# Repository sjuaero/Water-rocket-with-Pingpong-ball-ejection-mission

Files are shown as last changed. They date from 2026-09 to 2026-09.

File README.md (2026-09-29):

# Water Rocket with Ping-pong Ball Ejection Mission

A typical water rocket design designed to meet ping pong ball launch mission requirements.

1.5 L 페트병 하나를 동력원으로 **50 m 떨어진 목표 지점에 착탄**시키고, 비행 궤적상 **25 m 지점에서 탑재체(탁구공)를 사출**하는 물로켓을 설계·제작·발사한 팀 프로젝트입니다. CATIA로 구조와 사출 장치를 설계하고, MATLAB/Simulink와 OpenRocket으로 궤적·안정성을 예측한 뒤 실제 발사 결과와 비교해 오차 원인을 분석했습니다.

> 로켓공학및설계 (2026년 1학기) · 3인 팀 프로젝트

<p>
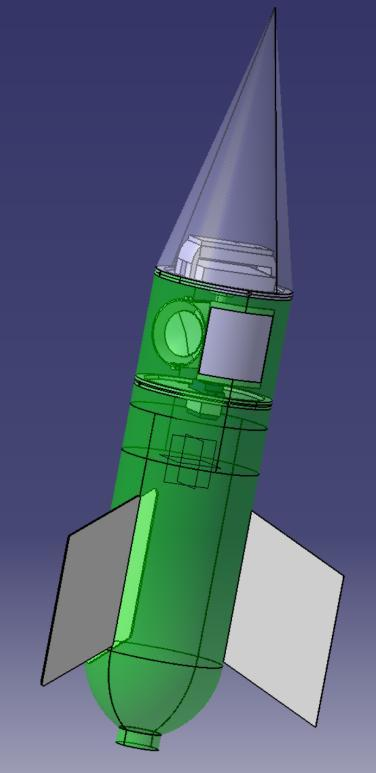
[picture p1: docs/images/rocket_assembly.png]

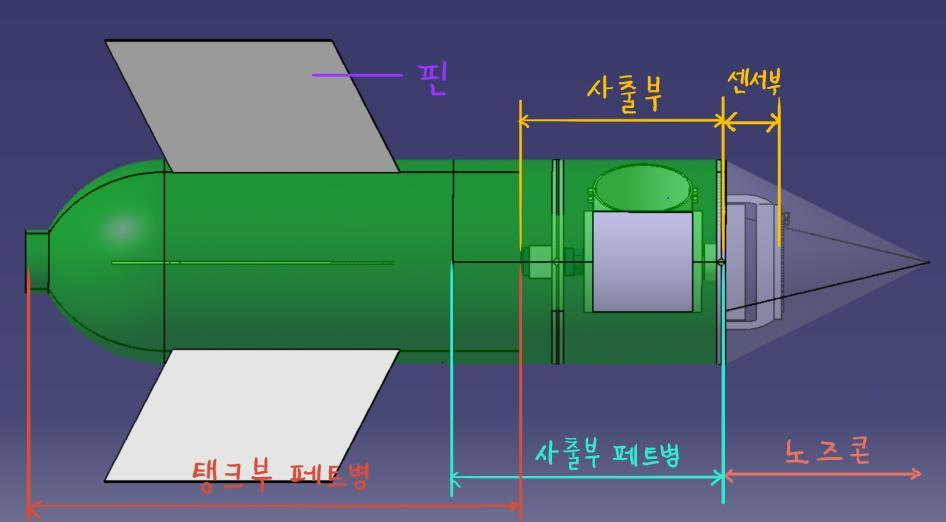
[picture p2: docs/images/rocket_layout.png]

</p>

---

## 미션 요구사항과 결과

| 항목 | 시뮬레이션 예측 | 실제 비행 | 차이 |
|---|---|---|---|
| 발사각 / 물 주입량 / 압력 | 50° / 0.58 L / 50 psi | 50° / 0.58 L / 50 psi | – |
| 최대 비행거리 (목표 50 m) | 49.04 m | **56.6 m** | +7.56 m |
| 총 체공시간 | 3.16 s | 3.8 s | +0.64 s |
| 탁구공 사출 시점 | 1.548 s | 2.05 s | +0.50 s |
| 탁구공 사출 위치 (목표 25 m) | 25 m | **약 23.7 m** | −1.3 m |

<p>
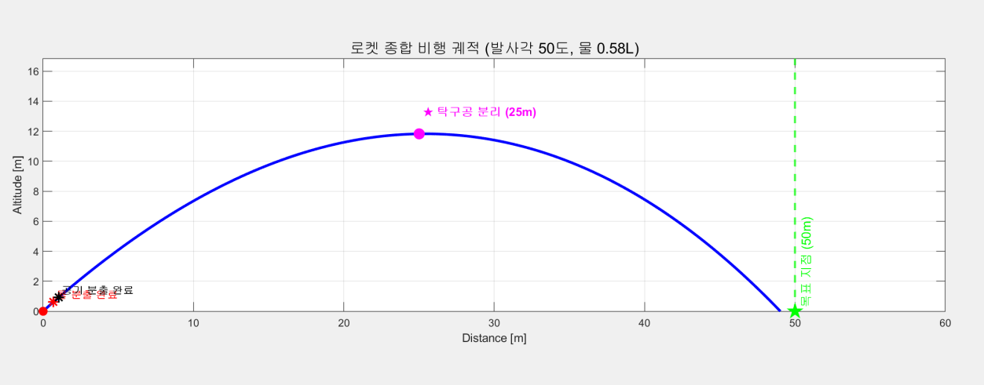
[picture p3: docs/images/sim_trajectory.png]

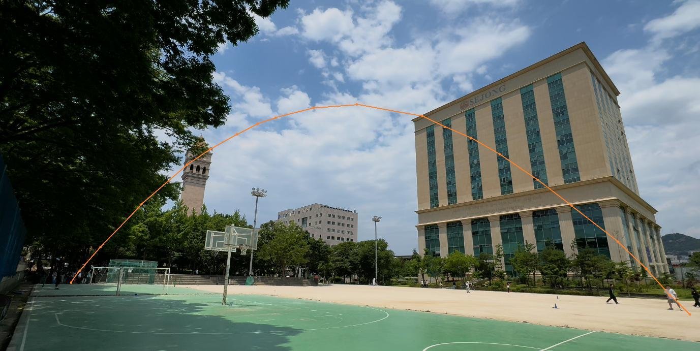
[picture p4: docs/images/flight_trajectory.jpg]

</p>

실제 비행 궤적과 사출 위치는 비행 중 BLE 통신 장애로 텔레메트리를 받지 못해 **촬영 영상을 프레임 단위로 분석해 복원**했습니다.

---

## 설계

### 1. 기체 구조와 비행 안정성

- **탱크부**: 칠성사이다 1.5 L 페트병을 가공하지 않고 사용했습니다. 50 psi에서 원주응력 38.81 MPa, 축응력 19.41 MPa로 PET 허용응력(약 89.7 / 66 MPa) 이내입니다. 반면 절단 후 접착하면 접합부 강도(테이프 0.154 MPa, 순간접착제 최대 4.2 MPa)가 부족해서 가공하지 않는 쪽을 택했습니다.
- **노즈콘**: 최대 속도 약 25 m/s(M ≈ 0.074)의 아음속이라 형상에 따른 항력 차이가 작습니다. 그래서 제작이 쉬운 원뿔형으로 하고, 직경 90 mm : 높이 180 mm(1 : 2)로 정했습니다. 소재는 경량 PP(클리어 파일)입니다.
- **무게중심 / 압력중심**: 부품별 실측 질량을 CATIA *Apply Material*에 밀도로 반영해 CG를 구했고(노즈콘 끝에서 **256.9 mm**), OpenRocket에서 CG를 override해 CP를 계산했습니다.
  - 물 0.58 L를 채운 직후에는 정적 마진이 −0.997 cal입니다. 다만 동압이 거의 0이고 물이 약 0.1 s 안에 모두 분사되기 때문에 영향이 작다고 판단했습니다.
  - 비행 중 안정 마진은 **0.243 ~ 0.276 cal**로, 전 구간에서 양수를 유지했습니다.

<p>
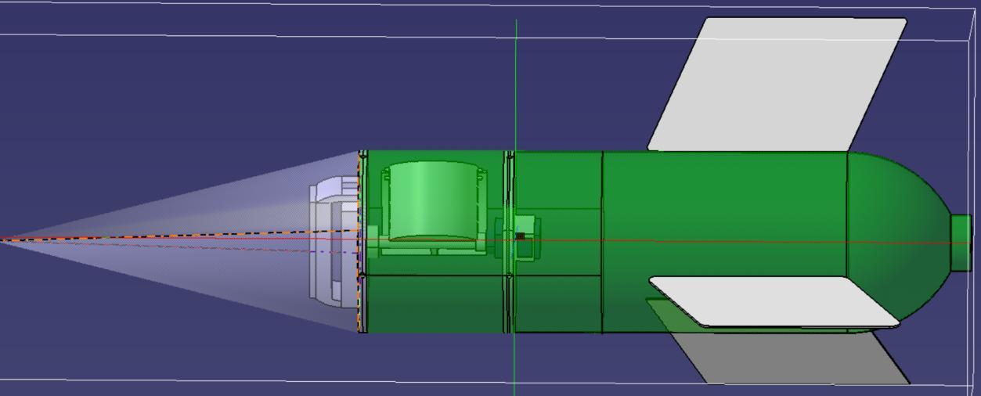
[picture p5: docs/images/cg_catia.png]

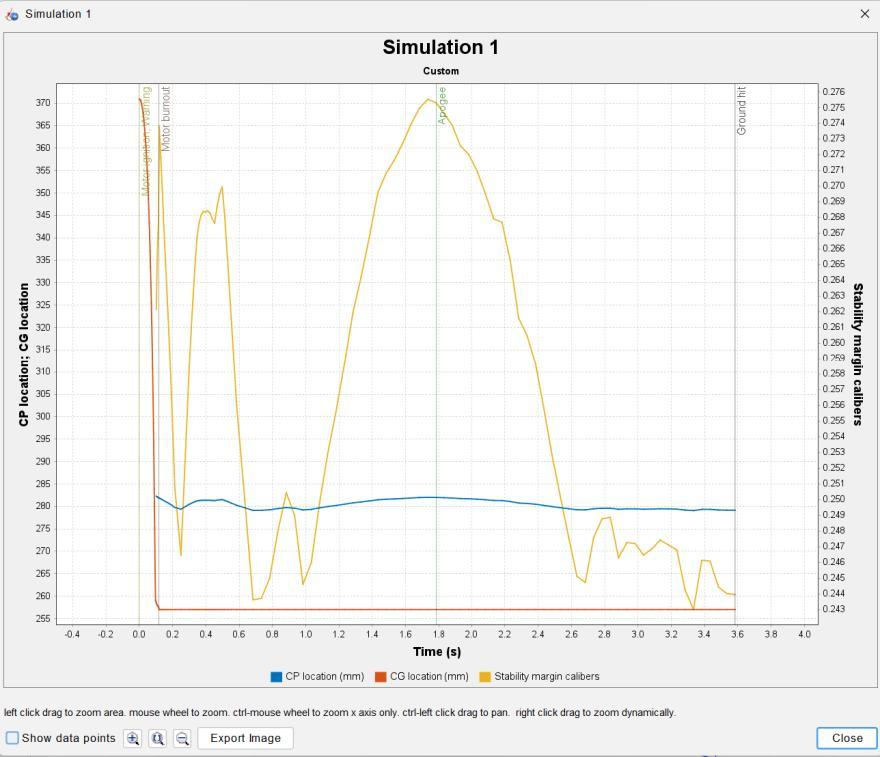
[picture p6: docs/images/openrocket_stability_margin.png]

</p>

### 2. 탁구공 사출 장치

두 가지 안을 설계했습니다.

| | 1안: 링크식 개폐문 + 스프링 | 2안(최종): 회전 실린더 + 슬링샷 |
|---|---|---|
| 방식 | 서보 → 평행 링크로 양쪽 문을 열고 스프링으로 밀어냄 | SG90 서보가 실린더를 회전시키면 고무줄에 걸린 Pusher Pad가 탁구공을 튕겨냄 |
| 결과 | 부품이 많고 작동 시간이 길어 **폐기** | 구조가 단순하고 가벼워 **채택** |
| CAD | [`cad/design_v1_link_door`](cad/design_v1_link_door) | [`cad/design_v2_final`](cad/design_v2_final) |

<p>
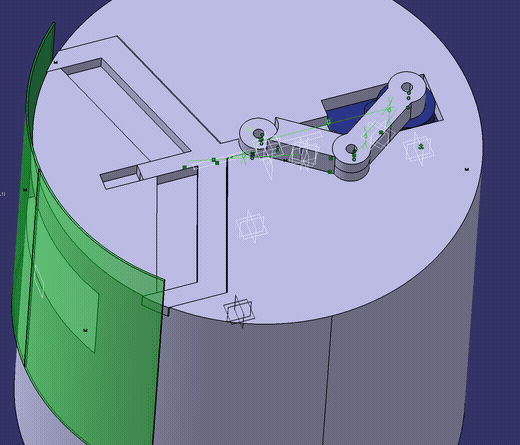
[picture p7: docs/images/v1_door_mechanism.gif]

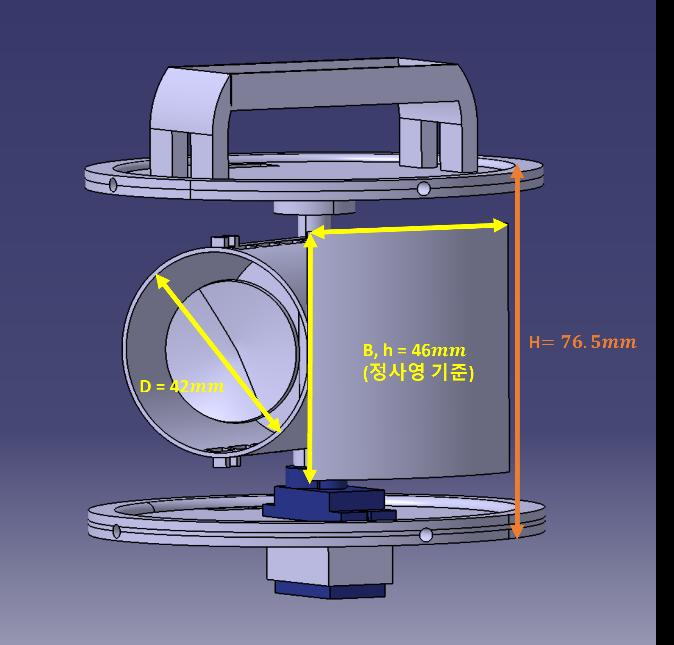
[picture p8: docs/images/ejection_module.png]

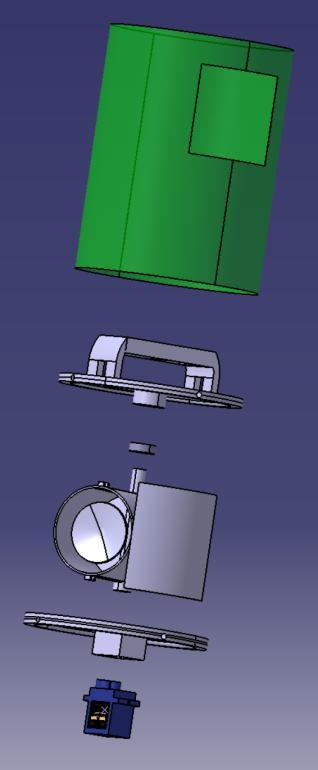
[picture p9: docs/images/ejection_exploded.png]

</p>

- 상판, 하판, 회전 실린더는 PLA+로 3D 프린팅했고, 상단 회전축에 베어링을 넣어 서보 출력에 따라 부드럽게 회전하도록 했습니다.
- 사출 지연 시간 예측값은 160.7 ms(고무줄 + 서보 + 전자장비 합산)입니다. 240 fps 슬로모션으로 측정한 값은 **167 ms**로, 예측과 7 ms 차이였습니다.

### 3. 비행 제어 및 데이터 수집 (Arduino Nano 33 BLE Sense)

IMU(가속도계·자이로)를 내장한 Arduino Nano 33 BLE Sense가 비행 컨트롤러 역할을 합니다. 로켓의 자세와 이동거리를 실시간으로 추정해 사출 서보를 구동하고, 비행 데이터는 BLE로 지상국(GCS)에 보냅니다. 상세 내용은 **[비행 소프트웨어 설계 문서](docs/flight_software.md)**에 정리했습니다.

```mermaid
stateDiagram-v2
    direction LR
    READY --> CALIBRATING: BLE 연결, 보정 명령
    CALIBRATING --> STANDBY: IMU 300샘플 평균
    STANDBY --> FLYING: 축방향 1.4 G 이상
    FLYING --> EJECTED: 27.7 m 또는 1.453 s
    EJECTED --> DUMPING: 1 G 1초 유지 (착지)
    DUMPING --> READY: 로그 전송 후 리셋
```

- **항법**: 자이로 적분으로 피치를 추정하고, 중력과 바이어스를 뺀 합성 가속도를 이중적분해 이동거리를 구합니다. 드리프트를 막기 위해 데드밴드 0.20을 적용했습니다.
- **사출 트리거**는 둘 중 먼저 만족하는 조건입니다.
  1. 추정 이동거리 **27.7 m** 도달 (직선 25 m에 해당하는 포물선 궤적 길이)
  2. 비행 시간 **1.453 s** 경과 (fail-safe)
- **데이터**:
  - 50 Hz로 최대 120 샘플을 RAM 버퍼에 저장합니다.
  - 착지 후 float을 int16으로 압축한 바이너리 패킷을 BLE로 보냅니다.
  - HTML 지상국 콘솔에서 로그를 받습니다.

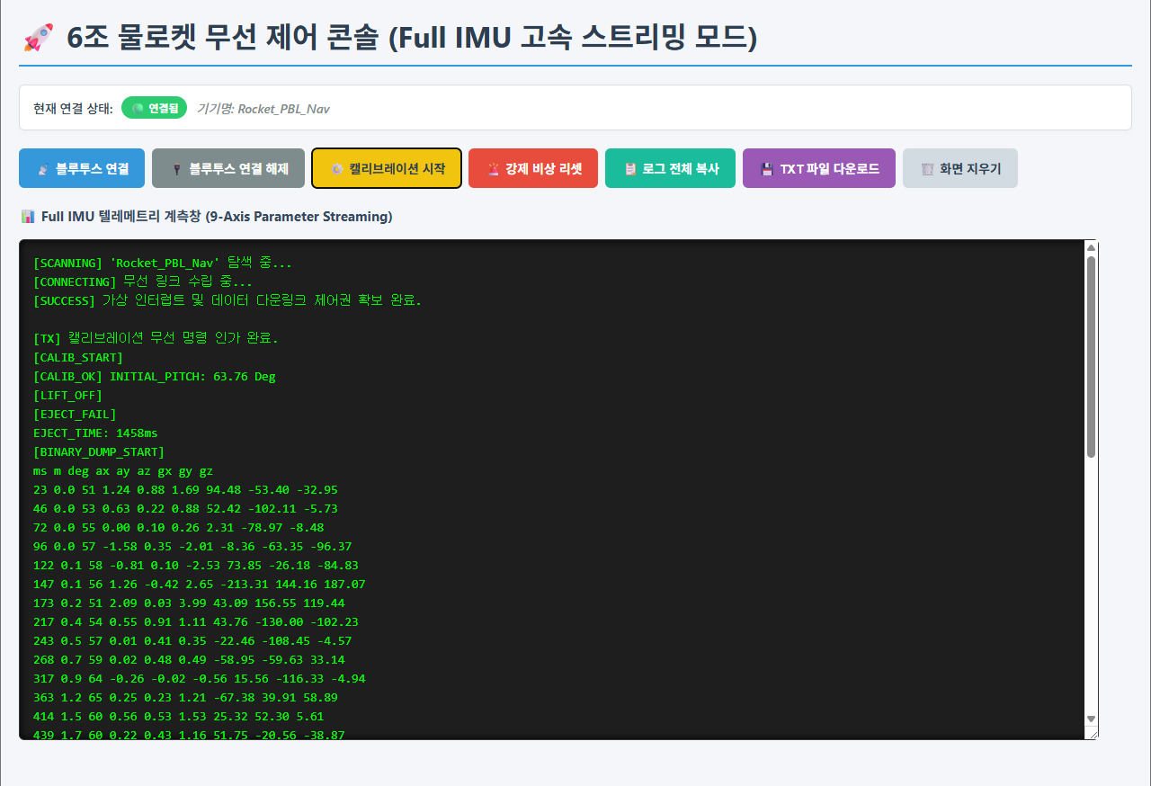
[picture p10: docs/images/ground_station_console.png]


---

## 오차 원인 분석

1. **배풍 효과**: 발사 당시 서풍 3 m/s가 불어 상대속도 기준 항력이 줄었고, 그만큼 비행거리가 늘었습니다.
2. **유량계수 과소평가**: 물/공기 유량계수를 1.0으로 두고 다시 계산하면 실제 비행거리와 0.5% 이내로 일치합니다. 다른 요인이 복합적으로 작용했다는 뜻으로 해석했습니다.
3. **사출 시스템 지연**: MCU 처리 시간과 서보 구동 지연이 시뮬레이션에 완전히 반영되지 않았습니다.
4. **발사 감지 지연**: 축방향 가속도 1.4 G를 넘어야 발사로 판정하기 때문에, 실제 발사 시각보다 늦게 타이머가 시작되었습니다. 그 결과 fail-safe 1.453 s 조건이 2.05 s에 작동했습니다.

---

## 시뮬레이션

<p>
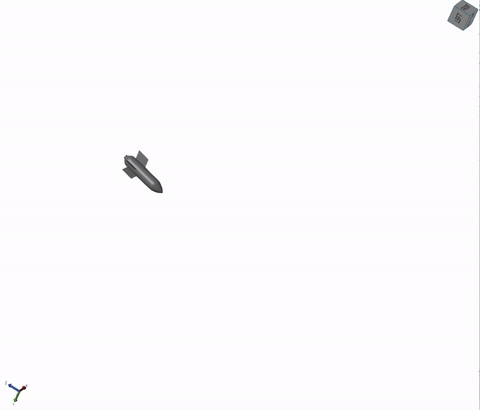
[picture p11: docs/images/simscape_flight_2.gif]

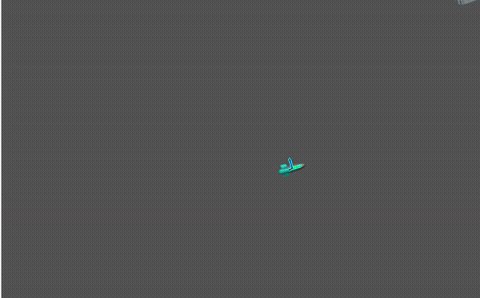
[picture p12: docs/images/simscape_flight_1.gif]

</p>
<p align="center"><sub>Simscape Multibody 6-DOF 비행 시뮬레이션 (<code>simulator_real.slx</code>, Mechanics Explorer)</sub></p>

| 파일 | 내용 |
|---|---|
| [`simulation/matlab/rocket3d_params.m`](simulation/matlab/rocket3d_params.m) | 추진·열역학·질량·CG·관성·공력 파라미터 (CATIA 측정값) |
| [`thrust_phase_func.m`](simulation/matlab/thrust_phase_func.m) | 물 분출 → 공기 분출 → 탄도비행 3단계 추력/질량유량 모델 (폴리트로픽 팽창) |
| [`aero_func.m`](simulation/matlab/aero_func.m) | Barrowman 선형화 3D 공력 모델 (항력 + 법선력 + 복원 모멘트) |
| [`mass_cg_inertia.m`](simulation/matlab/mass_cg_inertia.m) | 잔여 물 질량에 따른 질량·CG·관성텐서 보간 |
| [`stability_margin_timehistory.m`](simulation/matlab/stability_margin_timehistory.m) | 추력 구간 CG(t)–CP 안정 여유 시간이력 (단독 실행 스크립트) |
| [`water_simul.slx`](simulation/matlab/water_simul.slx) | Simulink 추력 모델 |
| [`simulator_real.slx`](simulation/matlab/simulator_real.slx) | Simscape Multibody 6-DOF 물로켓 모델 (**Simscape Multibody 필요**) |
| [`simulation/openrocket/water_rocket.ork`](simulation/openrocket/water_rocket.ork) | OpenRocket 모델. 물 0.58 L 추력곡선은 `motor/WaterRocket_0p58L.eng`로 불러오기 |

`mass_cg_inertia.m`은 `simulator_real.slx` 안의 MATLAB Function 블록 코드를 꺼낸 파일입니다. `stability_margin_timehistory.m`을 단독으로 실행할 때 필요합니다.

---

## 폴더 구조

```
Water-rocket-with-Pingpong-ball-ejection-mission/
├── cad/
│   ├── design_v2_final/        # 최종 기체 + 회전 실린더 사출 장치 (rotation_axis.CATProduct)
│   ├── design_v1_link_door/    # 1안: 링크식 개폐문 사출 장치 (link_dmu / ejection_assembly.CATProduct)
│   └── exports/                # 전체 기체 STEP·STL (zip)
├── simulation/
│   ├── matlab/                 # 추력·공력·질량 모델, Simulink / Simscape 모델
│   └── openrocket/             # .ork, 물로켓 추력곡선(.eng/.rse), CP-받음각 데이터
├── analysis/rubber_band_ansys/ # 슬링샷 고무밴드 ANSYS Workbench 해석
├── docs/
│   ├── flight_software.md      # 아두이노 비행 소프트웨어 설계 (FSM, 항법, 사출, 데이터 덤프)
│   ├── reports/                # 최종 보고서, PBL 개념설계(사출 메커니즘)
│   └── images/
└── coursework/nozzle_design/   # (같은 과목 개인과제) Bell vs Cone 노즐 설계, NASA CEA 분석
```

### CATIA 파일 열기

- CATIA V5에서 어셈블리(`.CATProduct`)를 열 때 파트 링크를 찾지 못하면 **File → Desk → Find**로 해당 폴더를 지정하면 다시 연결됩니다.
- `Arduino nano.CATPart`, `SG90 servomotor.CATPart`는 GrabCAD에 공개된 STEP 모델을 CATIA로 변환해 질량을 입힌 파일입니다.

## 보고서

- [로켓공학및설계 최종보고서](docs/reports/로켓공학및설계_최종보고서_6조.pdf)
- [비행 소프트웨어 설계 문서](docs/flight_software.md)
- [PBL 개념설계: 탁구공 사출 메커니즘](docs/reports/PBL_개념설계_탁구공_사출메커니즘.pdf)
- 개인과제: [노즐 설계 보고서 (Bell vs Cone)](coursework/nozzle_design/노즐_설계_보고서_Bell_vs_Cone.pdf) · [CEA 분석 보고서 (Equilibrium vs Frozen)](coursework/nozzle_design/CEA_분석_보고서_Equilibrium_vs_Frozen.pdf)

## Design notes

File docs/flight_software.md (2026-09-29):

# 비행 소프트웨어 설계 (Arduino Nano 33 BLE Sense)

물로켓의 비행 제어와 데이터 수집 소프트웨어 구조를 최종 보고서 내용만으로 정리한 문서입니다. 펌웨어 소스 코드는 포함하지 않습니다.

---

## 1. 하드웨어 구성

| 구성품 | 역할 |
|---|---|
| **Arduino Nano 33 BLE Sense** | 가속도계·자이로스코프가 통합된 IMU 기반 비행 컨트롤러(FC). 자세·이동거리 추정, 사출 판단, BLE 통신 |
| **SG90 서보모터** | 회전 실린더를 돌려 개폐문을 열고 탁구공을 슬링샷으로 사출 |
| **배터리 & 소켓** | 전원 (사출 장치 상단 공간에 장착) |
| **지상국(GCS)** | 웹 브라우저에서 동작하는 HTML BLE 콘솔 |

SD 카드 같은 내부 저장장치는 **발사체 질량을 줄이기 위해** 빼고, 모든 데이터를 BLE로 받도록 설계했습니다.

---

## 2. 유한 상태 기계 (FSM)

```mermaid
stateDiagram-v2
    direction LR
    READY --> CALIBRATING: BLE 연결, 보정 명령
    CALIBRATING --> STANDBY: IMU 300샘플 평균
    STANDBY --> FLYING: 축방향 1.4 G 이상
    FLYING --> EJECTED: 27.7 m 또는 1.453 s
    EJECTED --> DUMPING: 1 G 1초 유지 (착지)
    DUMPING --> READY: 로그 전송 후 리셋
```

| # | 상태 | 동작 |
|---|---|---|
| ① | `STATE_READY` | 하드웨어를 초기화하고 BLE 연결을 기다립니다. |
| ② | `STATE_CALIBRATING` | 정지 상태의 IMU 샘플 **300개**를 모아 초기 피치와 센서 바이어스를 계산합니다. |
| ③ | `STATE_STANDBY_DELAY` → `STATE_STANDBY` | 보정 직후 무선 통신 안정화를 위해 **500 ms 가드 타임**을 둔 뒤 발사 충격을 감시합니다. 축방향 가속도가 **1.4 G** 이상이면 발사로 판정합니다. |
| ④ | `STATE_FLYING` | 가속도·자이로로 이동거리를 실시간 계산하고 사출 조건을 감시합니다. |
| ⑤ | `STATE_EJECTED` | 서보를 구동해 탑재체를 사출하고, 착지할 때까지 충격 변화를 감시합니다. |
| ⑥ | `STATE_DUMPING` | RAM 버퍼에 쌓인 비행 데이터를 BLE 고속 패킷으로 전송하고 시스템을 리셋합니다. |

---

## 3. 비행 거리 추정 알고리즘

### ① 초기 자세와 센서 오차 (CALIBRATING)

지면에 정지한 상태에서 수집한 300개 샘플의 평균 $\overline{a}$를 씁니다.

```math
\theta_\text{init} = \operatorname{atan2}\!\left(\overline{a_{z,\text{raw}}},\ \overline{\sqrt{a_{x,\text{raw}}^2 + a_{y,\text{raw}}^2}}\right),
\qquad
\text{Bias}_z = \left(\overline{a_{z,\text{raw}}} - \sin\theta_\text{init}\right) g
```

### ② 비행 중 피치 추정 (FLYING)

정적 상태를 벗어나면 가속도로는 자세를 알 수 없습니다. 그래서 Y축 자이로를 시간에 대해 적분해 기울기를 갱신합니다.

```math
\theta_\text{current} = \theta_\text{prev} + \left(-\omega_y - \text{Bias}_{\omega_y}\right)\,dt
```

### ③ 3차원 동적 합성 가속도

원시값(g 단위)을 m/s²로 바꾸고, 추정 기울기에 해당하는 중력 성분과 바이어스를 빼서 **추력에 의한 가속도**만 남깁니다.

```math
a_x = a_{x,\text{raw}}\,g,\qquad
a_y = a_{y,\text{raw}}\,g,\qquad
a_z = \left(a_{z,\text{raw}} - \sin\theta_\text{current}\right) g - \text{Bias}_z
```

```math
a_\text{horizontal} = \sqrt{a_x^2 + a_y^2 + a_z^2}
```

### ④ 이중 적분으로 속도·거리 추정

```math
v(t) = v(t-dt) + a_\text{horizontal}\,dt,\qquad
s(t) = s(t-dt) + v(t)\,dt
```

- **노이즈 가드**: 가속도가 데드밴드(`ACCEL_DEADBAND = 0.20`)보다 작으면 정지로 보고 0으로 처리해 센서 드리프트를 1차로 억제합니다.
- 계산된 거리는 지구좌표계의 직선거리가 아니라 **궤적을 따라간 거리**입니다. 그래서 직선 25 m에 해당하는 포물선 궤적 길이인 **27.7 m**를 목표 거리로 정했습니다.

---

## 4. 사출 트리거

미션 실패를 막기 위해 두 조건 중 **먼저 만족하는 쪽**에서 서보에 신호를 보냅니다.

| 조건 | 값 | 목적 |
|---|---|---|
| 추정 이동거리 | **27.7 m** | 주 조건: 궤적상 25 m 지점 |
| 비행 시간 | **1.453 s** | fail-safe: 비행 시간이 짧고, 진동 같은 외란으로 거리 추정이 틀릴 경우에 대비 |

### 사출 지연 보정

| 구성 | 값 |
|---|---|
| 개념설계 예측: $t_\text{rubber} + t_\text{servo} + t_\text{elec}$ | 160.7 ms |
| 실측 (240 fps 슬로모션, 신호 → 탁구공 이탈) | **167 ms** (± $t_\text{elec}$ = 33.5 ms → 133.5 ~ 210.5 ms) |

- 예측과 실측 차이는 7 ms였습니다.
- 25 m 상공에서 33.5 ms가 만드는 거리 오차는 수 cm 수준이라 무시했습니다.
- 펌웨어에는 **167 ms 지연을 미리 빼서** 반영했습니다.

---

## 5. 데이터 저장과 덤프

| 항목 | 내용 |
|---|---|
| 로깅 주기 | 20 ms (**50 Hz**) |
| 버퍼 | RAM 배열, 최대 **120 샘플** (`MAX_LOG_SAMPLES`) |
| 착지 판정 | 사출 후 3축 가속도 크기 $\sqrt{a_x^2+a_y^2+a_z^2}$가 **1.0 G 부근에서 1000 ms** 유지 |
| 전송 방식 | 문자열 대신 구조체를 1바이트 배열로 직렬화한 **바이너리 패킷** (`bleWriteBinary`) |
| 압축 | float 값에 10 또는 100을 곱해 **int16**으로 전송 |
| 로그 형식 | `ms, m, deg, ax, ay, az, gx, gy, gz` (시간, 거리, 피치, 3축 가속도, 3축 각속도) |

### 지상국 (HTML BLE 콘솔)



- 상단 버튼: 블루투스 연결/해제, 캘리브레이션 시작, 강제 비상 리셋, 로그 전체 복사, TXT 파일 다운로드, 화면 지우기
- 하단 창: 로켓의 현재 상태(`CALIB_START`, `CALIB_OK`, `LIFT_OFF`, `EJECT_*`, `BINARY_DUMP_START`)와 비행 로그를 표시

---

## 6. 실제 운용 결과와 한계

| 항목 | 결과 |
|---|---|
| 지상 시험 | 사출 장치와 초기 시스템 구동은 정상이었고, 사양상 통신거리도 목표치(50~100 m)를 만족했습니다. |
| 실제 발사 | BLE 통신 장애로 유효 통신거리가 크게 줄어 비행 중 데이터를 안정적으로 받지 못했습니다. 대신 **촬영 영상을 프레임 단위로 분석**해 궤적과 사출 시점을 복원했습니다. |
| 사출 시점 | 설계 fail-safe는 1.453 s인데, 실제로는 **2.05 s(약 23.7 m 지점)**에 사출됐습니다. |

**원인 분석**
- fail-safe 조건만 있었다면 사출이 1.453 s를 넘을 수 없습니다.
- 그런데 2.05 s에 사출됐다는 건 **발사 시각을 늦게 인식**했다는 뜻입니다.
- 축방향 가속도가 1.4 G를 넘어야 발사로 판정하는 구조라서, 발사 → 감지 → 시간 측정 사이에 지연이 생긴 것으로 분석했습니다.
- MCU 처리 시간과 서보·개폐문의 기계적 지연도 시뮬레이션에 완전히 반영되지 않았습니다.

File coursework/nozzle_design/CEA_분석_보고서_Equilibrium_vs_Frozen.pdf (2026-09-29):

로켓공학및설계 CEA 분석 보고서

## CEA 분석 보고서

# NASA CEA를 이용한 로켓 노즐의

# Equilibrium 및 Frozen 조건 비교 분석

세종대학교 기계항공우주공학부

항공우주공학과

2026년 4월 17일

## 1. 환경 정의

- 1.1 공통 조건

: 먼저 로켓의 성능을 분석하기 위해 공통적으로 적용되는 가정이 있다.

1. 준 1 차원(Quasi-One Dimension) 상의 정상(Steady), 연속체 유동으로 가정한다.
2. 연소실(Chamber) 내 Total cond.로 가정하고 그 내부 속도를 없다고 가정한다.
3. 등엔트로피 과정인 가역단열 팽창이 발생함을 가정한다.
4. 이상 기체로 가정한다.
5. 연소실(Chamber) 내에서는 화합물 반응 간 화학적 평형이 유지된다.

위와 같은 가정들을 통해서 먼저 추진제 내 화합물 반응으로 발생되는 에너지 중 각 반응물마다 생성엔탈피의 차이를 단열가역 가정 내에서 최대한 에너지를 발생시키는 환경을 조성할 수 있다.

아래는 교안(강의자료#11)에서 제공한 해석 조건을 몇 가지를 제외하고 공통적으로 적용하게 된다.

파라미터 | 값 | 비고
연료 | H₂(L) | 액체 수소, 20.27K
산화제 | O₂(L) | 액체 산소, 90.17K
연소실 압력 (P) | 53.317 bar (773.3 psia)
O/F 혼합비 | 5.551 | 연료 농후 조건
압력비 (Pc/Pe) | 10, 100 | 두 가지 출구 조건
초음속 면적비 (Ae/At) | 25, 50 | 두 가지 노즐 출구
연소실 수축비 (Ac/At) | 1.58 | FAC 모드에서만 적용
계산 조건 | Shifting Equilibrium + Frozen | 두 조건 동시 계산

*FAC : Finite Area Combustor

- 1.2 해석 방식

### 1.2.1 Shifting Equilibrium (화학평형 해석)

노즐 팽창 과정에서 연속적으로 변화하는 압력과 온도 조건에 따라 모든 분자 화학종 사이의 화학 평 형이 순간적으로 유지된다고 가정하는 모델이다. 즉, 가스의 조성이 노즐을 따라 계속 변화(shift)하며, 연소실에서 존재하던 H, OH, O 등의 단원자 및 이원자가 재결합 반응을 통해 엔탈피를 추가로 방출함 으로써 더 많은 운동 에너지로 전환된다.

### 1.2.2 Frozen Composition (동결 조성 해석)

목(throat) 이후 노즐 팽창 과정에서 화학 조성이 고정(동결)된다고 가정하는 모델이다. 연소실에서 형 성된 조성이 그대로 유지되어 추가적인 화학 반응이 없으므로, 단원자 및 이원자의 재결합 에너지를 활용하지 못한다. 따라서 Shifting 조건 대비 성능이 1~4% 낮게 예측되는 보수적인 접근법이다.

### 1.2.3 Finite Area Combustor (FAC) 모드

마지막으로 진행되는 해석에서는 실제 연소실의 유한한 크기를 반영하기 위해 FAC 모드를 적용하였 다. 연소실-목 수축비(Ac/At = 1.58)를 입력하여 Injector face와 Combustor end 위치에서의 열역학 적 상태를 별도로 계산함으로써 교재 TABLE 5-4와 거의 동일한 구조로 진행하였다.

## 2. 해석 Input 설정

- 2.1 교안 35p, 36p 에 대한 Equilibrium/Frozen Input 설정

: Input 설정 과정을 사진으로 다 나타내는 것에 분량이 많아질 것을 우려하여 위에서 언급한 공통

조건을 교안에서 설명해두었던 방식 그대로 따라 적용하고 Final 탭에서 설정된 것을 확인하면 다음과 같다.

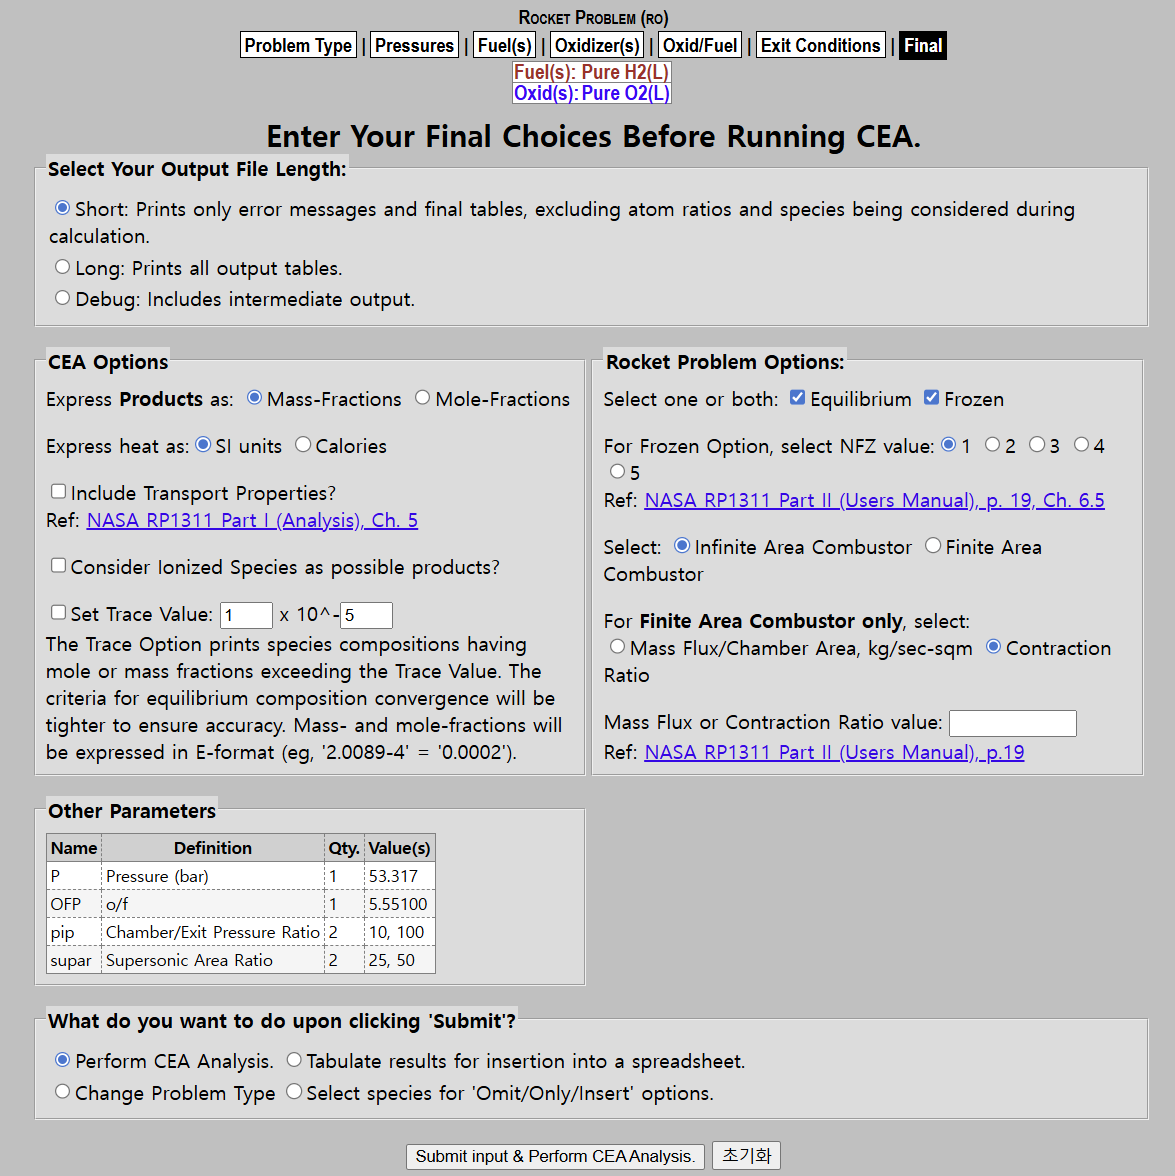
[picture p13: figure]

그림 1. 주어진 조건 하에서의 NASA CEA Equilibrium/Frozen 분석 Final Tap

먼저 위의 Short 설정을 통해 최종 결과 테이블만 출력하도록 하고, 아래 CEA Options 에서 연소 생성물 조성을 질량 분율로 표현하여 교안결과와 비교할 것이므로 Mass-Fractions 로 설정과 함께 SI Unit 으로 설정한다. 그 옆에서는 Equilibrium/Frozen 설정을 모두 키고 Frozen 의 경우는 Chamber 내에서만 가정하므로 ‘1’로 선택했다. 일단 Infinite area Combustor 로 설정해 앞서 가정해둔 Total Cond.를 유지하도록 한다. 그리고 아래 Other Parameters 에서 보이듯이 공통 조건이 잘 적용되어 있음을 확인할 수 있다.

- 2.2 교안 37p 예시에 대한 Input 설정

앞의 공통조건은 다 동일하게 적용하되, 바꾸어야 하는 조건은 Final Tap 에서 적용해야 한다. 적용된 변경점은 아래 사진을 통해 확인할 수 있다.

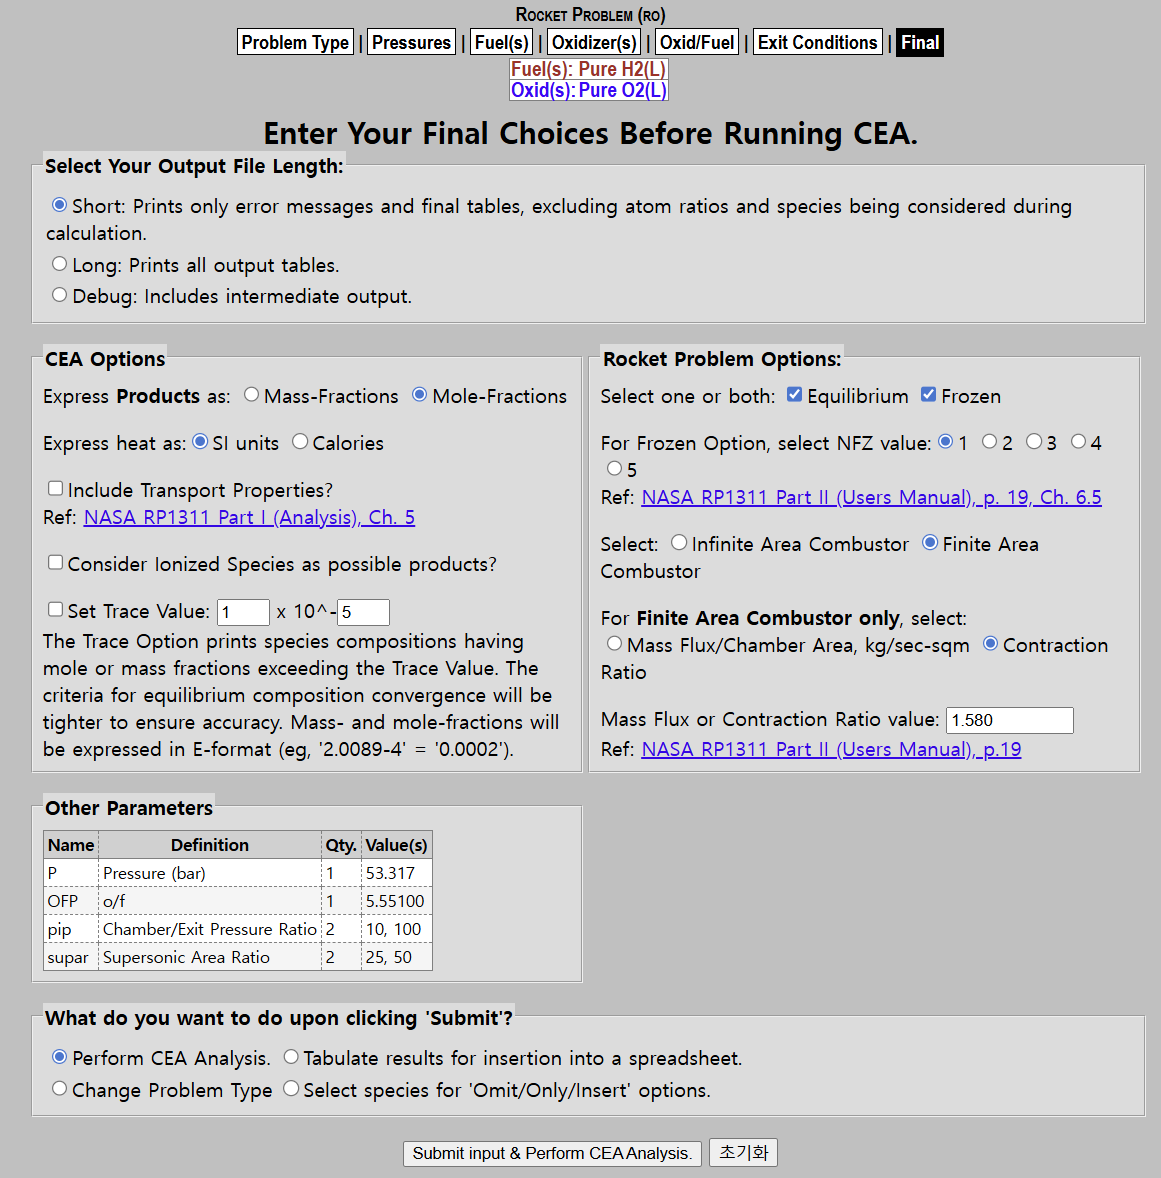
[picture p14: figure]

그림 2. 주어진 조건 하에서의 NASA CEA Finite Area Combustor 분석 Final Tap

이 경우에서는 일단 CEA Options 내 표현 방식을 Mole-Fractions 로 바꾸었다. 강의교안 #11 의 37p 에서의 예시에서 동일한 방식으로 표현되어 있어 이렇게 설정해두었다. 그리고 아래 Rocket Problem Options 에서 Finite Area Combustor 로 설정하였는데, 이렇게 되면 앞서 가정된 실제 유한한 크기의 연소실로 고려되므로 비-등엔트로피과정이 된다. 즉, 화학적 조성이 계속 변화하게 되므로 Equilibrium/Frozen 조건은 활성화되지 않는다. 이렇게 설정한 이유도 교안 37p 에서 주어진

연소실 수축비 조건에 의해 Injector 와 Combustion 에 대한 물성치가 활성화 된 것을 확인하고 이를 활성화하게 된 것이다. 그 아래에 수축비 1.580 을 대입한 것을 확인할 수 있다. 그리고 그 아래 Chamber 내 압력 및 추진제 화합물 비율 등의 공통 조건은 동일하게 적용되어 있다.

## 3. 해석 결과

먼저, CEA 프로그램 해석 결과에서 먼저 등장하는 것은 조건이 알맞게 적용되었는지 확인할 수 있다.

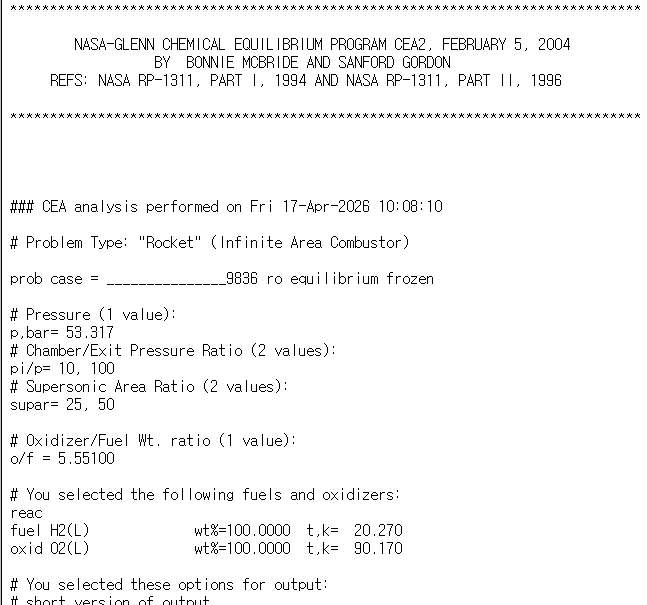
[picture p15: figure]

그림 3. 적용된 동일 물성치의 조건 확인

- 3.1 Infinite Shifting Equilibrium/Frozen Case and Finite Case 해석 결과

### 3 가지의 경우에 대한 CEA 결과는 동일 조건 하에서 몇가지만 조정된 채로 구한 각 챔버 및 목, 그리고

출구 단면적에서의 물성치 결과는 아래의 그림 4, 5, 6 과 같다. 교안과 비교했을 때 온도나 특성배기속도, 비추력 등에서는 소수점단위의 조금의 오차만 존재하여 오차율이 매우 작은 소수정도로 나타났다. 따라서, 결과적으로 유의미한 결과를 얻었다고 판단할 수 있다.

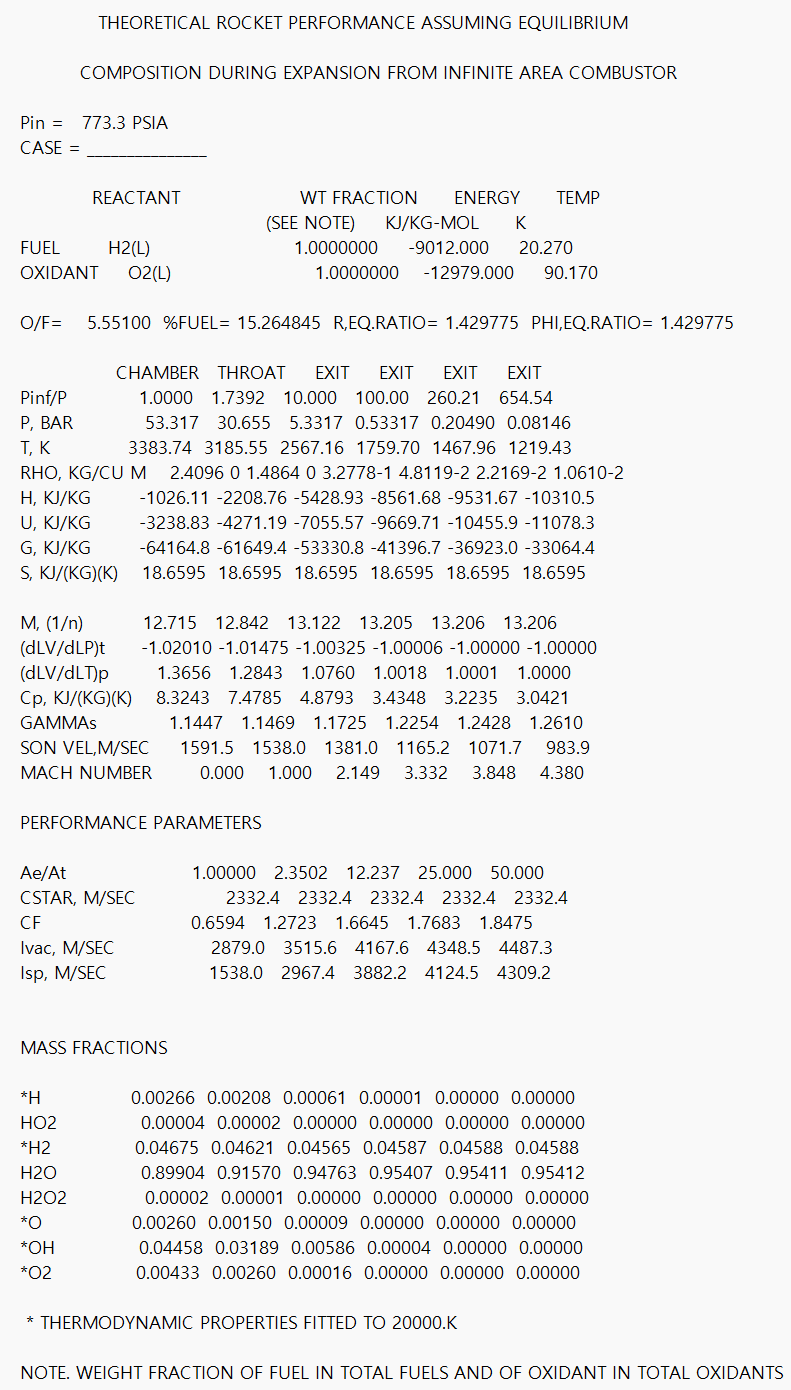
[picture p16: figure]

그림 4. Infinite Shifting Equilibrium 조건 상에서의 해석 결과

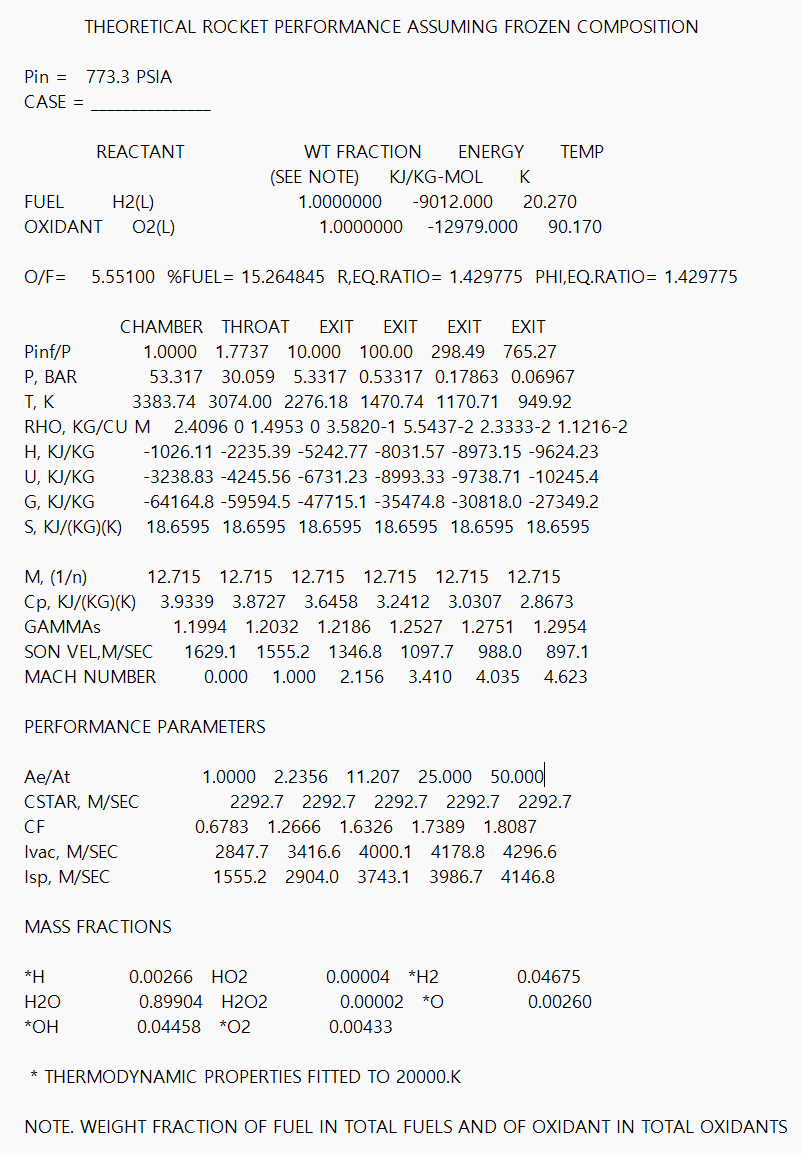
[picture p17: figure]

그림 5. Infinite Frozen 조건 상에서의 해석 결과

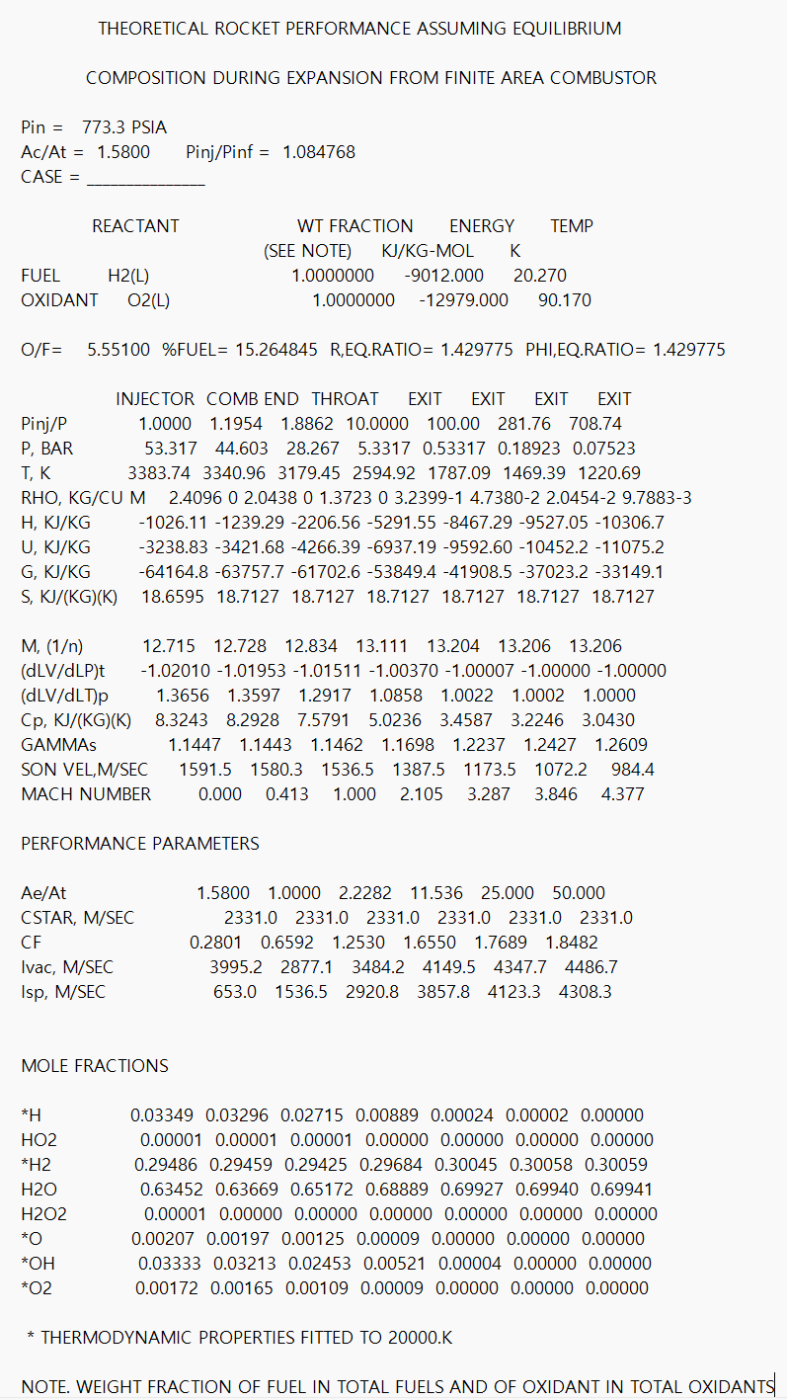
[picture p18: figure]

그림 6. Finite 조건 상에서의 해석 결과

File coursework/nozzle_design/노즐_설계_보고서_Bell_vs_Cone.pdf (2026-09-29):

로켓공학및설계 노즐 설계 보고서

## 노즐 설계 보고서

# 동일 조건 상 Bell 과 cone 형상 노즐 간 차이

세종대학교 기계항공우주공학부

항공우주공학과

2026년 3월 26일

## 1. 노즐 파라미터 계산

- 1.1 공통 조건

: 먼저 각 형상별 함수를 구하는 과정은 Matlab 상에서 m 단위를 기준으로 계산하였다.

주어진 조건 r* = 0.1m, r_e = 1m, L = 2m 의 길이 제한과 더불어, 노즐목 부근에서의 형상 반경은 xy 좌표계 기준 (0,0.2)에서의 r* 반경을 가지는 원호를 radian 기준 [6/4pi, 7/4pi] 사이에서만 나타내어야 한다.

- 1.2 이차함수형 Bell 형 곡선 구하기

: 위 공통 조건과 함께, 다음의 조건을 적용시켜야 한다.

조건 1. 원호의 끝점과 이차함수의 시작점이 일치해야 함.

조건 2. L = 2m 인 노즐 끝의 y 좌표는 r_e = 1m 로 맞추어야 함.

조건 3. 원점으로부터 L = 2m 만큼 떨어진 위치에서의 이차함수 곡선은 기울기가 0.

다음과 같은 조건들을 통해 세 개의 방정식을 있고, 아래와 같이 행렬계산으로 바꾸어 이차함수

y = Ax

2 + Bx + C

의 미정계수를 구할 수 있게 된다.

먼저, 원호와 곡선 간 만나는 지점을 x_c, y_c 라 하면, 주어진 각도 theta = pi/4 에 따라

x_c = r ∗ cos(theta)

y_c = 0. 2 − r ∗ sin(theta)

그럼 3 개의 조건식에 대한 방정식을 나열하면,

조건 1 : A ∗ x_c

2 + B ∗ x_c+ C = y_c

조건 2 : A ∗ L

2 + B ∗ L + C = r_e

조건 3 : 2A ∗ L + B = 0

[

x_c

2 x_c 1
L
2 | L | 1
2L | 1 | 0

][

A
B
C

] = [

y_c
r_e
0

]

위 행렬식을 matlab 에서 역행렬을 구하는 \(역슬래쉬) 계산을 통해 미정계수를 구하였다.

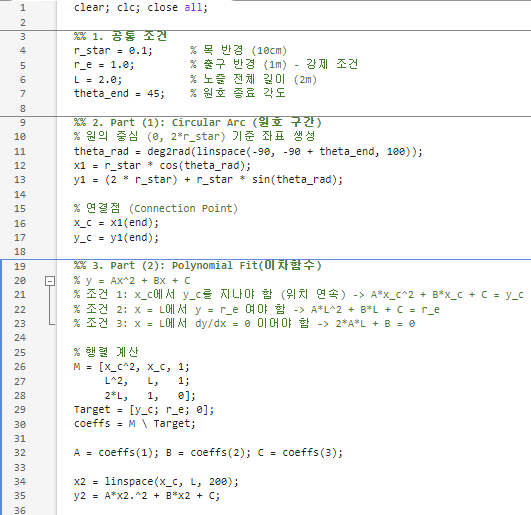
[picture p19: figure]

그림 1. 이차함수형 Bell 미정계수 구하는 코드

### - 1.3 일차함수형 Cone 형 직선 구하기

앞서 공통 조건에서 L 은 미지수가 되어 조건이 줄어들지만 일차함수를 구하기에 경계 조건과 미지수는 동일하게 만족된다. 먼저 a = 15 도의 cone angle 이 주어졌으므로 이 일차함수의 기울기는 tan(15°) 가 된다. 그리고 앞서 조건 1. 원호의 끝점과 이차함수의 시작점이 일치해야 함. 을 이용하여 일차함수의 형태를 구할 수 있게 된다.

y = tan(15°)x + a

접촉점(xc
, yc

) ⇒ yc = tan(15°) ∗ xc + a , a = y_c − tan(15°) ∗ xc

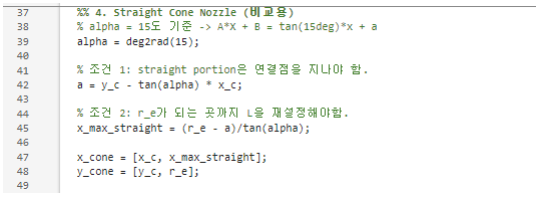
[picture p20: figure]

그림 2. 일차함수형 Nose 미정계수 구하는 코드

- 1.4 미정계수 결과 및 plot, 결과 비교

다음 시각화 과정을 통해 각 노즐형상 별 미정계수 및 cone 의 총 형상 길이를 구한 결과 아래와 같다.

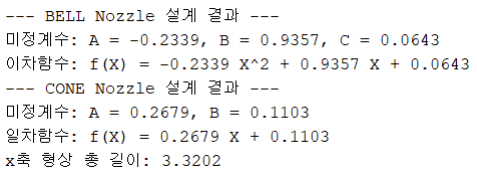
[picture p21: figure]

그림 3. 미정계수 결과 및 길이 비교

공통 조건을 만족시킬 때, 이차함수 bell 형태일 때의 L = 2m 보다 약 1.3202m 더 길게 cone 의 총 형상 길이를 3.3202m 로 형상설계해야 함을 알 수 있다.

이상추력 대비 실제 추력에 대한 비율을 의미하는 the correction factor λ (https://namu.wiki/w/%CE%9B) 를 고려해보았을 때,

동일한 면적비 기준에서 Bell 형상의 경우 노즐 출구에서의 곡선이 수평하게 끝나도록 만들었기에

λ
bell (https://namu.wiki/w/%CE%9B)

=

1
2

(1 + cos 0) = 1

여기에 원추형 노즐의 경우에서는 일정 각도 15 도로 설계하였으므로, 출구에서의 factor 는

λ
cone (https://namu.wiki/w/%CE%9B)

=

1
2

(1 + cos 15°) = 0.983

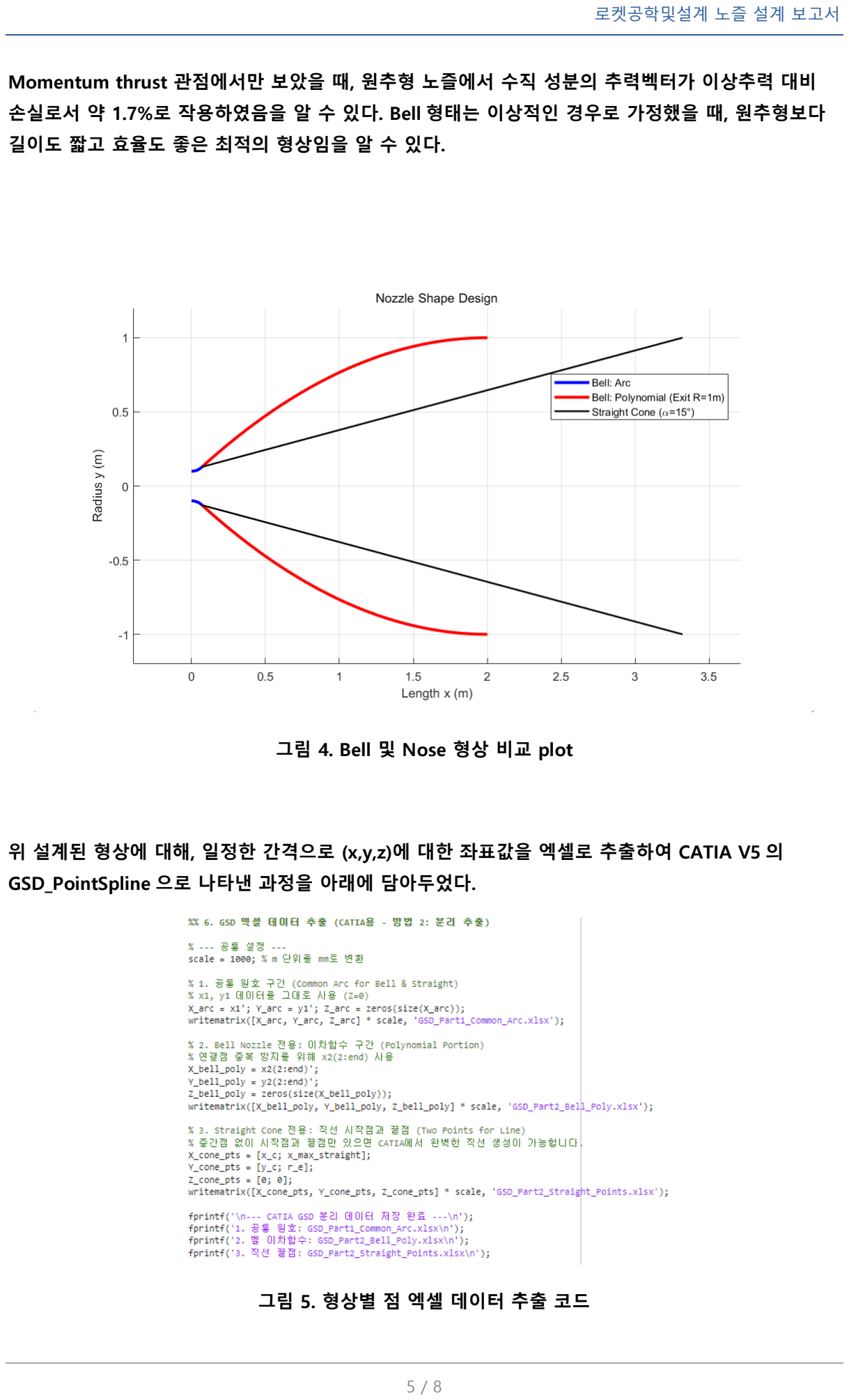
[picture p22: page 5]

Momentum thrust 관점에서만 보았을 때, 원추형 노즐에서 수직 성분의 추력벡터가 이상추력 대비 손실로서 약 1.7%로 작용하였음을 알 수 있다. Bell 형태는 이상적인 경우로 가정했을 때, 원추형보다 길이도 짧고 효율도 좋은 최적의 형상임을 알 수 있다.

그림 4. Bell 및 Nose 형상 비교 plot

위 설계된 형상에 대해, 일정한 간격으로 (x,y,z)에 대한 좌표값을 엑셀로 추출하여 CATIA V5 의 GSD_PointSpline 으로 나타낸 과정을 아래에 담아두었다.

그림 5. 형상별 점 엑셀 데이터 추출 코드

여기서 공통된 원호 엑셀 데이터, Bell 형 데이터, 원추형 데이터로 나누어 생성한 이유는 각각 Bell 형 데이터 점 데이터 집합, 원추형 데이터 점 집합을 CATIA V5 에 생성할 경우 Spline 이 그 원호와 곡선 간 접점 부근에서 잘못 인식하여 생성하는 문제점이 발생하곤 한다. 이를 방지하고자 각각 생성하여 JOIN 을 통해 하나의 곡선으로 합칠 것이다. 아래는 다운받은 점데이터를 GSD Spline 을 생성해주는 엑셀 데이터에 옮겨 spline 을 CATIA V5 상에 구현한 뒤 Shaft 기능을 통해 두께 1mm 의 노즐 형상으로 만든 것이다.

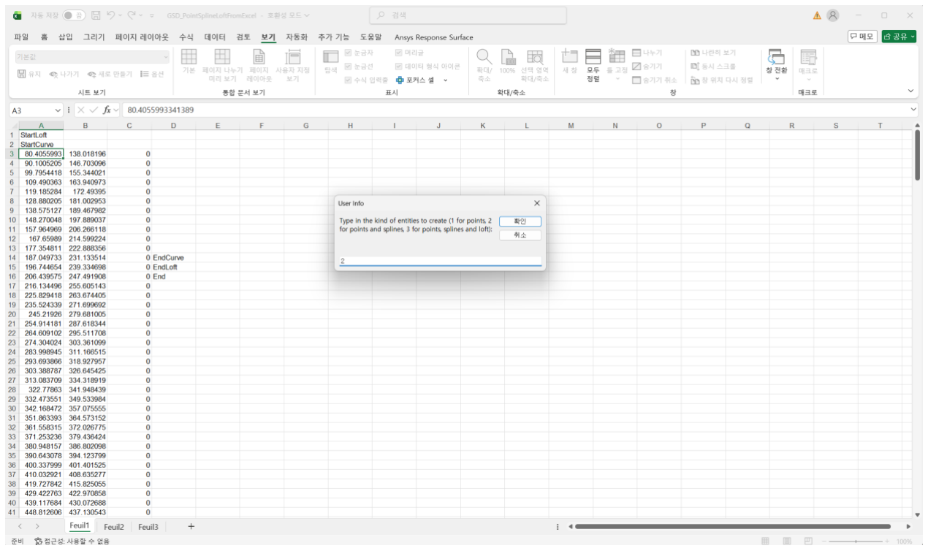
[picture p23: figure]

그림 6. 다운받은 점 엑셀 데이터를 GSD_PointSpline generator 로 옮겨 생성하는 사진

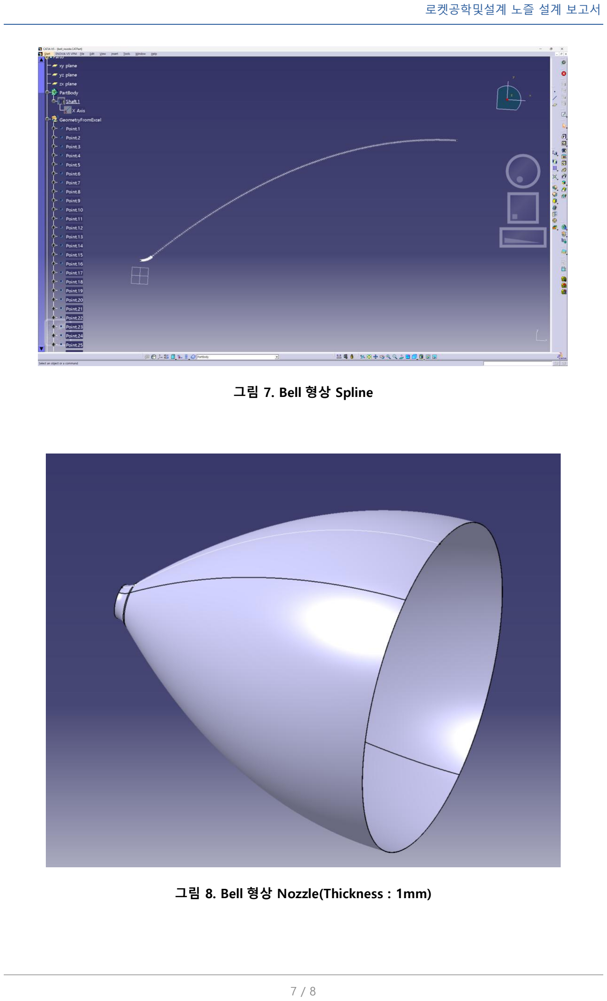
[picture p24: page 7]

그림 7. Bell 형상 Spline

그림 8. Bell 형상 Nozzle(Thickness : 1mm)

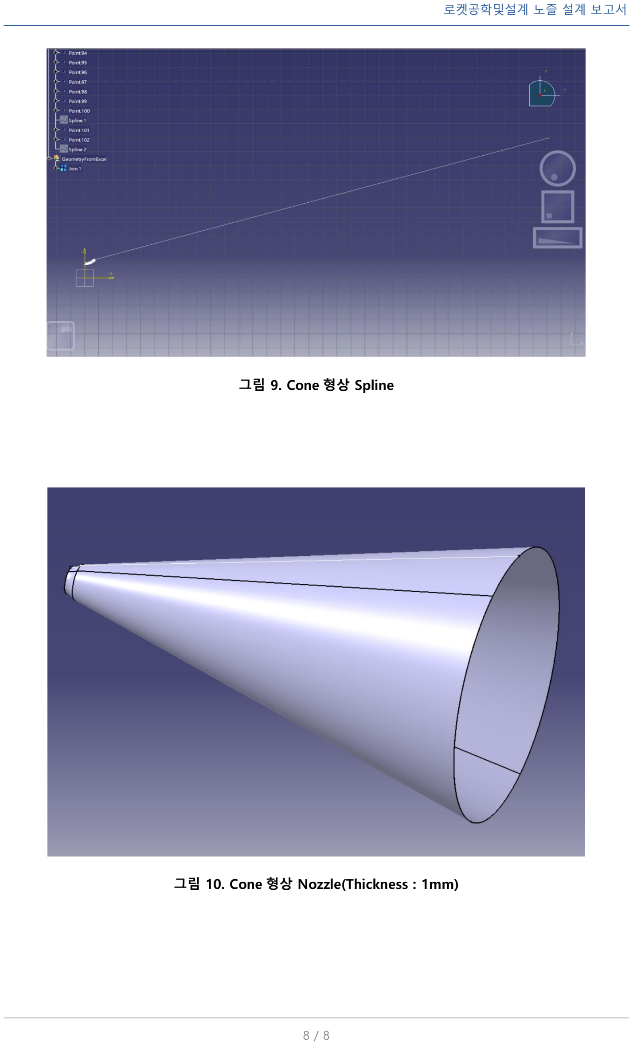
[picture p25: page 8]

그림 9. Cone 형상 Spline

그림 10. Cone 형상 Nozzle(Thickness : 1mm)

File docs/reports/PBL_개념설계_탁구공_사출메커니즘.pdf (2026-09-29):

2-7-1 탁구공 사출 매커니즘

추진체를 통한 우주 공간상에서 탑재체를 사출하는 과정은 특정 고도에 정밀하게 도달 함과 동시에 주로 탑재체로 쓰이는 위성이 방출되는 시점에 배출 축에 수직된 방향으로 각운동량이나 선운동량이 거의 없게끔 하여 위성의 자세까지 섬세하게 고려해야 한다. 하나의 예로, 캐나다의 우주항공솔루션 기업 MDA의 소형 위성 사출 목적의 Payload Ejection System(PES)을 들여다보면 페이로드의 질량중심이 기하학적 중심과의 편차로 방 출되는 순간 생기는 Tumbling(우주공간에서 모멘트에 의해 회전하거나 뒤집힘) 현상을 해결하기 위해 non-parallel hinge pairs를 사출 방식을 택했음을 알 수 있다. 이는 기존 가이드 레일 시스템이나 스프링 사출 방식의 한계점을 극복하는 점이라 할 수 있다. 이 에 대한 원리를 간단히 확인해보면 탑재체를 지탱하는 Base plate와 탑재체를 밀어내는 Release plate가 항상 평행을 유지하며 분리되도록 하는 동역학적 구속 조건을 설정하여 질량중심(COM)위치와 무관하게 유효 힘 벡터가 탑재체의 질량중심을 통과하도록 자동 조정하는 메커니즘을 제공한다.

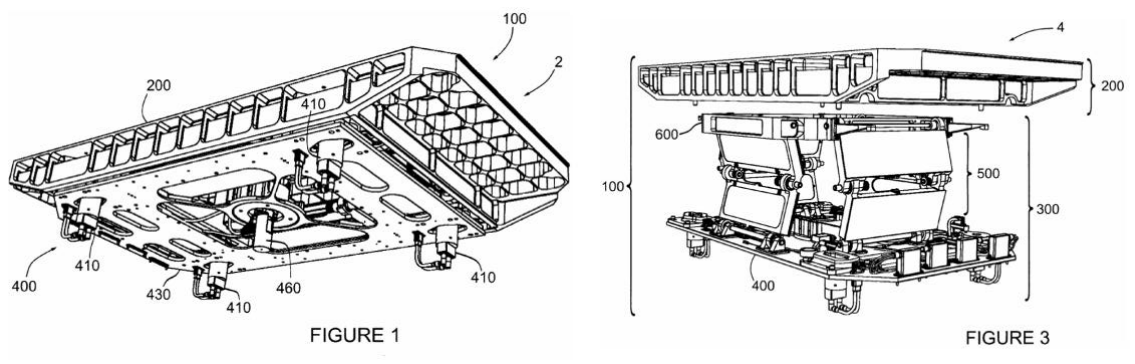
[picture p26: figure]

그림 1. PES메커니즘, 특허 US20190352025A1, 제조사 MacDonald Dettwiler and Associates Inc

하지만, 본 PBL 임무 과정에서는 탑재체인 ‘탁구공’을 물로켓이 고속으로 날아가는 과 정에 있어 특정 고도에 사출되어야 한다. 즉, 속도 조절이 불가능한 상태에서 거의 정확 한 비행 고도 25m에서 정확한 타이밍에 사출되야만 한다는 것이다. 그렇기에 앞서 보여 진 예시처럼 탑재체의 회전 운동을 고려하기 보단 특정 고도 도달 직전에 로켓의 속도와 자세 데이터 및 기압계의 측정 데이터, 그리고 사출 방식 메커니즘의 작동 시간 및 외란 등을 최대한 고려하여 비행 고도 25m에 근접하게 탁구공이 사출되도록 하는 것이 우선 시되어야 한다.

이번 사출 방식 모델링의 첫 번째 핵심으로 고려한 것은 간단한 사출 시스템을 구성하 는 것이다. 처음 사출 시스템을 고안한 당시, 서보모터의 동력을 전달하는 링크 케이지를 덧달아 연결하여 자동 차폐문 및 Trigger 방식의 스프링 사출 시스템을 생각하였지만, 팀

원과의 의논을 통해 복잡한 메커니즘일수록 생각치 못 한 고려사항을 놓쳐 사출에 실패 하거나 작동 시간이 오히려 더 길어질 수 있어 특정 고도 사출에 민감하게 반응하지 못 할 수 있다는 판단을 내렸다. 따라서, 우리 조에서 고안한 방식은 아래 설명그림과 같이

Slingshot ejection 시스템을 적용하였다. Spring ejection 시스템도 가능하겠지만, 무게적 으로 Slingshot 구조가 상대적으로 작고 들어갈 부품과 매커니즘 또한 간단해지기 때문 에 이를 택했다.

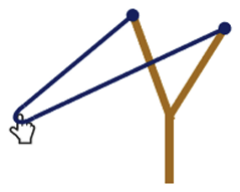
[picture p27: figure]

그림 2. 전형적인 Sling shot 형태

제작 및 진행 과정은 다음과 같다. 첫 번째 그림과 같이 먼저 탁구공의 공식 규격 기 준인 직경 40mm의 구가 사출될 수 있도록 페트병의 평평한 면을 그 영역에 맞게 잘라 낸다. 그리고 그 페트병 안에 탁구공을 담는 실린더를 배치한다. 그리고 그 실린더 옆에 페트병을 잘라 나온 곡면을 안정적으로 고정한다. 이 곡면이 하나의 회전문 역할을 하게 되는 것이다. 이 실린더는 하단의 서보모터에 의해 회전이 가능하며, 임무 수행 전에는 닫힌 상태로 있다가 25m에 근접할 때, 미리 설정한 알고리즘에 의해 실린더가 회전하여 탁구공이 있는 위치가 사출 영역으로 회전하여 움직이게 된다. 그리고 실린더 가장자리 양쪽에 고무줄을 통과시켜 묶은 다음 고무줄의 가운데에 탁구공을 밀어내는 Pusher Pad 를 부착한다. Pusher Pad는 실린더에 탁구공이 삽입된 상태에서 회전되어 벽면에 대한 반력에 의해 기존 위치보다 뒤쪽에 위치하게 되며, 연결되어 있는 고무줄이 팽팽해진다. 이는 앞서 말한 Slingshot 발사 메커니즘을 자연적으로 유도한다.

(아래 그림은 사출 메커니즘을 이해하기 위해 간략하게 필요한 부품만 나타내었다.)

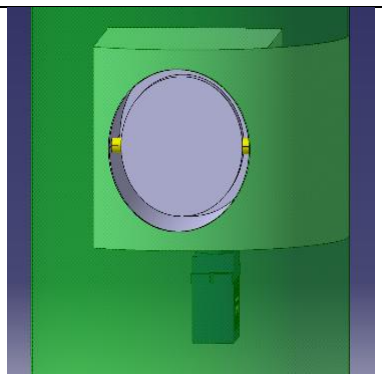
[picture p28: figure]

탁구공 삽입 전
실린더 상태

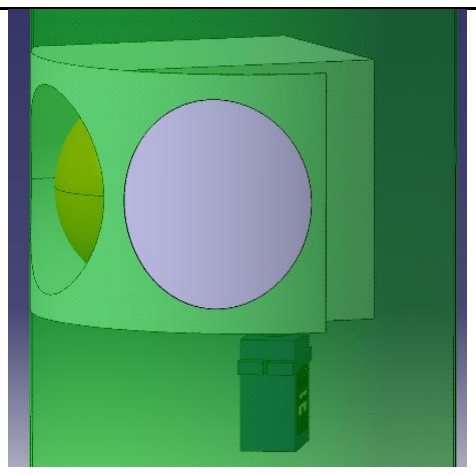
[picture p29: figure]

탁구공 삽입 후
실린더 회전

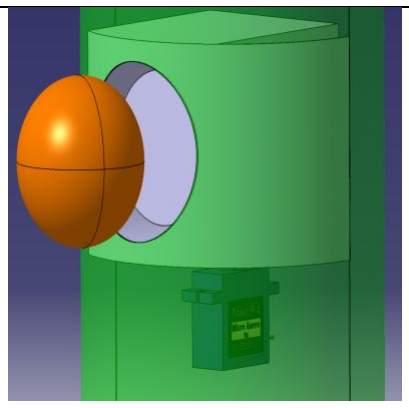
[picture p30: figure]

실린더 회전과 동시에
탁구공이 사출됨

그림 3. Slingshot 구조 사출 방식 메커니즘

앞서 탁구공 사출 고도인 25m에 도달하는 시간이 대략적으로 1.1~1.2초 내에 존재하 는 것을 알 수 있다. 이에 대해 사출 방식 모델링의 두 번째 핵심으로 둔 것은 앞서 말 한 기압계부터 회전된 실린더에서 탁구공이 사출되기 직전까지 거치는 모든 통신 및 기 계적 과정에 걸리는 시간을 이론적으로 구하고 이를 반영해 알고리즘을 설계할 계획이 다. 먼저 개념설계를 위해 실린더 내부에 담긴 탁구공의 사출 시간을 분석해본다.

2-7-2 탁구공 사출 시간 trubber

이 과정에서는 실린더 내부에 장착되어 있는 Pusher Pad와 연결된 고무줄이 벽면에 의해 당겨진 상태였다가 실린더가 돌아가고 탁구공이 완전히 사출되기 직전까지 걸리는 시간을 구해본다. 실제 실린더를 평면도 기준으로 내려다보았을 때, 당겨진 Pusher Pad 의 내부 상태는 다음과 같다. 이는 Sling shot 구조를 보여준다.

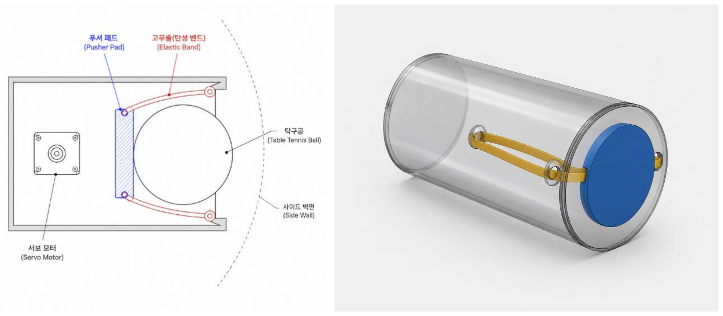
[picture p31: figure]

그림 4. Slingshot 구조 사출 실린더 | 그림 5. 3D 형태로 보는 실린더 형태

먼저 탁구공의 관점에서 받고 있는 고무줄은 보통 비선형 초탄성 재료로서 변형률에 따 라 탄성계수E가 달라지는 특성이 있다. 이는 변형률이 매우 높은 몇백프로에서도 파단이

일어나지 않음을 의미한다. 인장과 압축의 두 상태를 복합적으로 해석하는 방식은 고무 줄의 기하학적 형상을 정확히 예측할 수 없다. Xi’an 건축공과대학교의 Xiang Li 외 3인의

논문 ‘Dynamics of Rubber Band Stretch Ejection’에서 Sling shot의 역학적 원리를 분석하 고자 고무줄을 가느다란 빔의 형태인 오일러-베르누이 빔 형태로 가정하여 고무줄 자체 가 늘어난 상태에서 튕겨 나갈 때의 시간에 따른 곡률 관계를 분석한다. 이후 기존 굽힘 을 무시한 가정에서의 탄성파 속도 C 대비 고무줄 후단의 수축 속도 V의 비 V/C에 FEM(Finite Element Method)를 통한 해석결과를 선형보간법에 의해 구해진 굽힘에 대한 보정계수 a = 1.09를 곱하여 분석했다. 하지만 이는 FEM의 분석에 쓰인 고무줄의 물성치 가 다르므로 그대로 수학적 계산에 대입할 수 없다. 하지만, 알 수 있는 것은 위 그림과 같이 고무줄의 굽힘 해석의 결과가 선형적 탄성 결과에 비해 약 9%의 영향만 존재한다 는 것으로 알 수 있다. 만약, 매우 긴 변형률로 고무줄을 크게 당겨 발사하지 않는 이상, 이러한 고무줄의 굽힘 효과는 미미하다고 볼 수 있다. 특히 42mm 정도의 실린더 내부 에서는 더더욱 고려할 대상은 아닐 것이다. 따라서, 이번 수학적 모델링에서는 굽힘 효과 를 반영하지 않은 채로 인장 및 수축에 따른 비선형 탄성력만 가해진다고 가정한다. 그 리고 고무줄의 구간별 장력은 동일하게 작용한다고 보고, 패드는 실린더의 축방향으로 평행하게 이동한다고 가정한다. 그리고 고무줄의 질량은 20cm 기준 저울로 측정한 결과 0.083g이고, 이는 Pusher Pad(3D프린팅 슬라이싱 기준, 5g)와 탁구공(2.7g)의 합 7.7g 대 비 약 1.1%의 질량을 차지하므로 고무줄의 관성 효과는 크지 않아 보여 이를 무시할 수 있다. 그리고 마찰 및 공기저항 등의 외력은 무시한다. 이 또한 계산해보면 큰 값을 가지 지 않음을 알 수 있다.

그렇다면 먼저 변형길이가 0인 평형 상태의 지점(그림 5.)을 Pusher Pad가 움직이지 않 은 상태로 한다. 이때, 길이가 거의 변형되지 않는 상태에서 고무줄이 팽팽하게 패드를 실린더의 중실축에 수직하도록 유지시킨다고 가정한다.

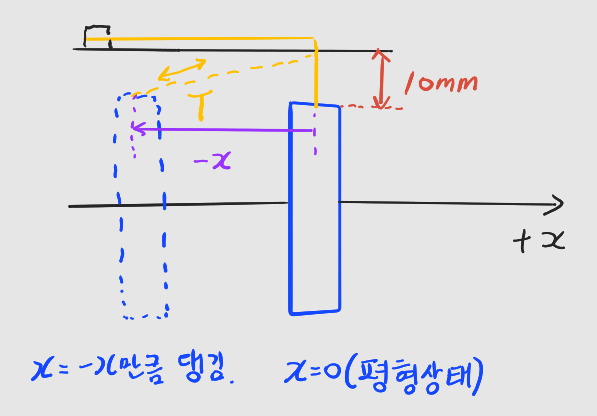
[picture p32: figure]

그림 6. 사출방향(+x축) 에 반대의 x방향 변위를 가지는 늘어난 스프링(점선)

위에 나타난 그림처럼 사출방향(+x축)에 반대로 고무줄이 당겨지기 때문에 -x축의 변위 를 갖는다. 그러면서 발생되는 장력 T를 구하고 이를 뉴턴 제 2법칙을 이용해 가속도 함 수를 구할 수 있게 된다. 이를 적분하여 속도를 얻는 과정을 진행할 것이다. 구멍에서 Pusher Pad 사이의 거리 10mm를 고무줄의 자연 길이 Lnat으로 b의 길이와 동일하게 설 정한다. 이는 제작 과정에서 조건을 만족하기 위해 변동될 수 있다. 여기에 변위 -x만큼 변한 고무줄의 길이는 피타고라스 법칙에 따라,

## L(x) = √x

2 + b

2

여기서 b는 실린더와 패드 간 사이의 거리를 의미한다. 즉, 위 길이 L(x)는 실린더 내 부에서 늘어난 길이를 의미한다. 이를 통해 우리는 변형률을 구할 수 있게 된다. 여기에 신장비 λ(x)에 대한 함수로 나타내면 다음과 같다.

ℰ(x) =

L−L0
L0

## = λ(x) − 1, λ(x) =

√x
2+b

2

L0

이를 가지고 고무줄에 걸리는 수직응력 σ =

T
A

= Eℰ , 즉 장력 T는 아래의 식을 가진다.

## T(x) = EAℰ(x) = EA{λ(x) − 1}

여기서 알고 싶은 것은 패드를 축방향으로 되돌아가게 하는 복원력을 알고 싶은 것이 다. 이를 계산하기 위해 삼각비를 적용한다. 여기서 복원력은 고무줄의 개수 n에 따라 선 형적으로 비례하는 특성을 지니므로,

## F(x) = nT(x)

−x L(x) = nEA(−x){ | 1 Lnat −

1
| √x
2 + b

2

}

이는 곧 패드가 받는 실린더 축방향의 힘이 되며, 반대쪽 고무줄도 축방향에 대칭이므 로 두 배의 힘을 패드에 전달하게 된다. 패드가 탁구공가 접촉된 상태로 사출되므로 뉴 턴 제 2법칙에 따라,
(mball + mpad)ẍ= 2nEA(−x){ | 1 Lnat −

1
| √x
2 + b

2

}

좌변에 모든 항을 이항시키면,

## (mball + mpad)ẍ+ 2nEA{

1

Lnat

−

| 1 √x 2 + b

2

}x = 0

하나의 비선형 운동방정식이 만들어지게 된다. 이는 손으로 풀기에는 어려움이 존재 하므로 Runge-kutta 4 방식을 적용해 수치해석적 과정을 거치는 과정을 아래와 같이 수 행하였다. 여기서 고무줄의 탄성계수는 위에 언급된 논문에서 흔히 사용하는 노란색 고

무줄의 탄성계수 범위 E = 1~5MPa 중 1.1MPa을 설정하여 사용하였다. 또한, 노란색 고 무줄의 두께를 측정해보니 약 1.78mm로 나오는 것을 확인하였고, 이를 정사각형의 단면 적이라 가정하면 A = d

2 = 3.2 × 10⁻⁶m² 로 산출되게 된다. 탁구공의 공식 질량은 27g =

0.027kg이고, 고무줄은 두가닥을 사용하므로 n=2가 된다. 축방향으로 최대한 늘어나는 길이는 탁구공의 직경과 동일하므로 d = 40mm로 설정한다. 이러한 파라미터 값들을 정 리하면 아래와 같다.

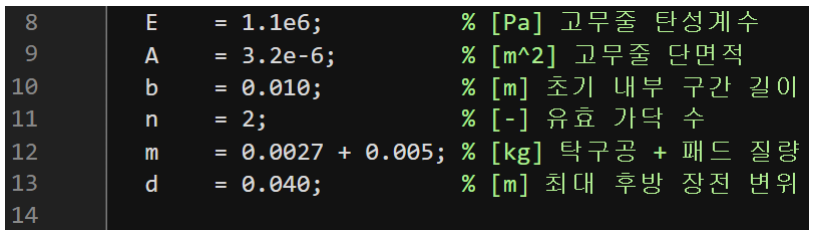
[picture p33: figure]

그림 7. 기본 파라미터 값 설정

Runge kutta 4 수치 적분을 적용하기 위해 1계 연립으로 나타내면 다음과 같다.

d
dt (

x
ẋ

) = (

ẋ
F(x)

M

)

초기 조건 x(0) = −d, ẋ(0) = 0 이므로 이를 통해 matlab 내 ode45 함수를 사용해 결과를 구하였다.

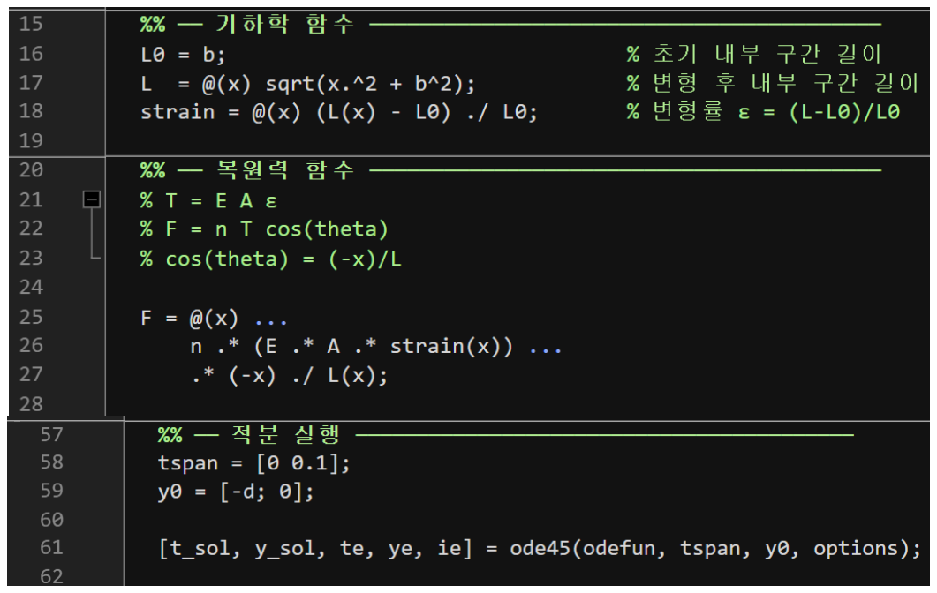
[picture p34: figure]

그림 8. Ode45 설정 코드

이를 통해 구한 y값(축방향 값)이 0이 되는 시점, 즉 패드가 평형상태로 정지해 있는 지점에 처음 도달할 때 탁구공이 완전히 빠져나가는 시점이 되므로 조건문을 통해 이때 의 시간과 그때의 속도 y_dot을 구하여 결과를 산출하였다.

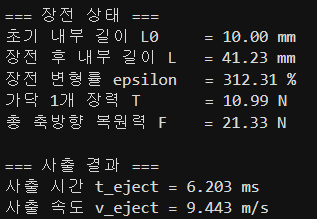
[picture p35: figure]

그림 9. 사출 시간 및 사출 속도 결과

결과적으로 매우 작은 값인 약 6ms, 0.006s를 지님을 알 수 있다. 하지만, 이는 기하학 적으로 선형의 탄성력을 가지는 이상적인 가정과 탁구공이 받을 외력을 고려하지 않은 값이므로 이를 반영해주어야 한다.

2-7-2 역학적 고려사항

앞서 계산한 사출 시간은 실린더 내부에서 Pusher Pad가 탁구공을 바깥으로 완전히 밀 어내는 경우만 분석하였다. 하지만, 전체적인 시스템으로 해석하면 대기 상에서 추진중인 로켓 내에서 탁구공이 사출되는 것이다. 이 시스템 내에서는 여러 가지의 고려 사항이 발생하게 되는데, 앞서 언급한 마찰은 누르는 패드보다 탁구공의 질량이 더 작으므로 탁 구공의 마찰력을 크게 이겨낼 수 있다는 직관적인 해석으로 무시가 가능하며, 공기저항 의 경우 사출속도 9.443 m/s 및 대기압 기준 Re값에 따른 항력계수를 선정하여 계산한 다. 이는 Anderson 저자의 Fundermental of Aerodynamics 책을 참고하여 구하였다.

Re =

v×d
ν

=

9.443×0.04
1.5×10⁻⁵ = 25181, 구 형상의 10⁴ < Re < 10⁵ 의 경우 CD = 0.47

FDrag =

1
2

ρairv

2CDAball =

1
2

(1.225)(9.443)

2

(0.47)(π × 0.02²
) = 0.0321N

복원력 F = 21.33N으로 가속된 탁구공에 단 0.01%도 영향을 미치지 못하므로 이를 무 시할 수 있다.

그리고 출구면에 대해 바깥 기압으로 들어오는 공기의 압력을 이겨내며 사출될 수 있 는지도 고려해보아야 하는데, 이는 동압(Dynamic pressure)에 따른 힘을 계산하면 유추할 수 있다. 탁구공이 나아가며 생기는 압력차는 동압과 같으므로,

∆P =

1
2

ρv

2 =

1
2

(1.225)(9.443)

2 = 54.62Pa, Fp = ∆P × Aball = (54.62) × π(0.02)

2 =
0.077N

즉, 이 또한 0.01%에도 항력 기여를 하지 못하므로 무시 가능하다.

이외에도 로켓 자세에 따른 중력과 실린더 회전에 따른 원심력도 고려해보아도 아래의 값들처럼 고무줄에 의한 복원력에 한참 못 미치는 수준이다.

(아래의 각속도는 그림 10. 제원의 무부하의 경우를 반영하였고, r은 회전축과 공 중심 거리를 Catia 상에서 계산해 넣은 값이다.)

Gball = mball × g × sinφ = mball × g = (0.0027)(9.81) = 0.026N (수직한 자세, 최대)

FCentri = mball × ω

2 × r = (0.0027)(

60π
0.12 × 180

)

2
(0.021) = 4.32mN

2-7-3 서보모터 작동 시간 tservo

이번 실린더의 회전과 개폐문의 핵심 동력원으로 사용하게 될 서보모터 SG90의 제원은 아래와 같다.

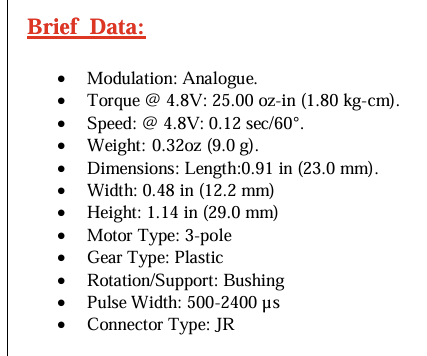
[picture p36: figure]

그림 10. SG90 서보모터 제원

여기서 보이다시피 토크와 각속도의 제원을 바로 한눈에 확인할 수 있다. 여기서 서 보모터에 무부하의 각속도는 60도 회전 기준 0.12초가 걸림을 알 수 있다. 실제로 지금 설계중에 있는 실린더의 중심축과 사출영역의 중앙 간 각도를 60도로 맞추어 두었다.


그림 11. 실린더와 사출영역 간 각도 = 60°

그렇다고 이 0.12초를 그대로 작동 시간으로 계산하면 좋겠지만, 이는 무부하의 각속 도이므로 서보모터에 장착될 실린더의 질량과 질량관성모멘트로 토크를 다시 계산하고 그에 따른 각속도를 다시 재계산해야한다. 먼저 현재 정확한 실린더의 재질, 크기는 정해 지지 않았기에 추후 정확하게 계산되어질 예정이나, 현재 대안으로 만들어둔 실린더를

CATIA의 측정 기능 및 3D프린터 Bamboo studio의 슬라이싱 질량 체크 기능으로 질량과 관성모멘트를 측정하였다.


그림 12. 실린더의 관성모멘트 측정값


그림 13. PLA+ 필라멘트 소재 실린더의 질량

그림 12의 여러 관성모멘트 값들 중에서 저 실린더의 Z방향 중심축에 서보모터를 연 결할 것이므로 IozG 값을 사용한다. 여기서 주의할 점은 CATIA상의 질량 0.034Kg에 대 한 IozG = 1.955 × 10⁻⁶kg × m² 이므로, 실제 질량 m = 0.045kg으로 다시 재계산하면,

IZZ = (1.955 × 10⁻⁵
) ×

0.045
0.034

= 2.557 × 10⁻⁵kg × m²

여기서 서보모터에 사용되는 DC 모터는 보통 토크와 속도간 선형 반비례 관계를 가

지므로 다음의 관계식을 지닌다. 아래의 τstall은 앞서 제원의 모터가 버티는 최대 토크

값, ωnoload는 무부하 각속도이다.

τ = τstall × (1 −

ω

ωnoload

)

그리고 회전에 대한 운동방정식은

τ = I

dω
dt

위 식을 대입해주고 정리하면,
dω
dt =

τstall
I

× (1 −

ω

ωnoload

)

이는 전형적인 DC모터가 가지는 1차 선형 ODE 형태를 보여준다. 이를 시간 t에 대한 라플라스 적분으로 다시 정리해서 시간에 따른 각속도의 함수를 표현하면 아래와 같다.

ω(t) = ωnoload × (1 − e

−t/τc )

여기서 τc 는 토크의 개념이 아닌 시간상수이며, 시간상수가 작을수록 모터의 속도가 점점 더 빨라짐을 알 수 있다. 라플라스 계산 과정 중 치환된 이 시간 상수는 아래와 같 으며, 단위는 시간이다.

τc = tservo = I

ωnoload

τstall

= (2.557 × 10⁻⁵
)

60π
0.12 × 180
0. 177

= 1. 26ms

다음으로 위에서 구한 시간에 따른 각속도 함수를 회전각으로 적분하면,

θ(t) = ωnoload × {t − τc
(1 − e

−t/τc )}

앞서 60도(=π/3)를 회전해야 출구 영역에 도달하므로

π
3

= ωnoload × {t − τc
(1 − e

−t/τc )}

t >> τc(1.26ms)의 작동시간이므로 지수항은 0으로 근사시킬 수 있다. 즉,

π
3

= ωnoload × (t − τc
)

위에서 구한 값들을 대입하여 t를 구하면,

t servo =

π
3(8.73)

+ 0.00126 = 0.12126s = 121ms

2-7-4 항전장비 작동 시간 telec

앞서 로켓 구성 파트에서 언급된 데이터 흐름도를 따라 Arduino Nano 33 BLE Sense에 장착되어 있는 기압계에서 얻은 고도데이터가 MCU를 걸쳐 조건문을 판독 후 서보모터 로의 명령 송출까지의 작동 시간을 구해본다.

2-7-4-1 기압계 센서(LPS22HB) 샘플링 시간

:LPS22HB데이터시트에 따르면, 260~1260hPa의 대기압 측정범위와 2.44 × 10⁻⁴mbar의 정밀한 분해능을 가진다. 또한, 아래 사진에서 볼 수 있듯이 최대 75Hz의 출력 데이터율 (ODR)을 지원하므로 샘플링 주기는 다음과 같다.


그림 14. LPS22HB 제원

tsample =

1
f

=

1
75

= 13.3ms

이렇게 샘플링된 고도 데이터는 I2C 통신 방식에서 400kHz로 전달되는 시간은 0.2ms 정 도로 명시되어 있다.

2-7-4-2 MCU(nRF52840) 연산 처리 시간

:MCU는 내장된 CPU와 메모리, 입출력 회로가 한 칩에 집적되어 있어 매우 빠른 데이 터 처리 속도를 보인다. 아래 Nrf52840의 데이터시트 제원을 보면 64MHz로 어마어마한 통신 속도를 자랑한다.


그림 15. Nrf52840 제원

환산하면 1사이클당 15.6ns로 연산처리 자체의 시간은 무시해도 무관하다.(조건문을 읽는 과정을 포함)

또한, MCU에서 서보모터(SG90)로 동작을 수행하도록 하기 위한 PWM 신호값으로 보내 야 하는데, 이는 아래의 SG90의 제원에서 나타난 PWM 주기를 확인하여야 한다. 왜냐하 면 MCU가 PWM 신호를 결정하지 않고 연결되는 장치별 신호에 맞추어 신호를 내보내 기 때문이다.


그림 16. SG90 제원

50Hz마다, 즉 20ms마다 PWM 신호를 읽어 내므로 MCU에서 서보모터로 명령을 전송 해 서보모터가 인식하기까지 최대 20ms가 걸린다는 뜻이다.

결론적으로 항전장비 작동시간을 모두 합산하면,

telec = 13.3 + 0.2 + 20 = 33.5ms

최종적으로 탁구공이 특정 고도 25m를 인지하여 사출되기까지 걸리는 시간은 다음과 같다.

ttotal = trubber + tservo + telec = (6.203) + (121) + (33.5) = 160.7ms

이는 0.1607s로 너무나 작은 시간이라 생각될 수 있지만, 앞서 시뮬레이션에서 25m 지점 부근까지 걸린 시간이 1초 초반대라는 것을 생각하면 적지 않은 시간임을 알 수 있다. 이는 추후 결정되는 설계 파라미터 값들과 그에 따른 시뮬레이션 결과를 토대로 시간을 재선정하여 아두이노 코드에 지연시간으로 사출 시간을 조금 더 빠르게 할 수 있 도록 할 예정이다.

5. 출처
[1] Li, X., Sun, B., Zhang, Y., & Dai, Y. Dynamics of Rubber Band Stretch Ejection. Research Square. https://doi.org/10.21203/rs.3.rs-517306/v1
[2] LPS22HB, DataSheet, MEMS nano pressure sensor: 260-1260 hPa absolute digital output barometer (https://www.st.com/resource/en/datasheet/lps22hb.pdf)
[3] Nrf52840, DataSheet, NRF52840.PDF
[4] SG90, DataSheet, SERVO MOTOR SG90 DATA SHEET (http://www.ee.ic.ac.uk/pcheung/teaching/DE1_EE/stores/sg90_datasheet.pdf)

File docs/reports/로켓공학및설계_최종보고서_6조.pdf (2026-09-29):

목차

## 1. 서론

### 1.1 연구 목적

본 보고서는 1.5L 페트병 1개를 주 동력원으로 활용하여 출발점으로부터 50m 떨어진 목 표 지점에 정확히 착탄시키고, 비행 궤적 상 25m 지점에서 탑재체(탁구공)를 정밀하게 사출하는 물로켓의 최종 설계 및 발사 결과를 다룬다. 앞서 진행된 예비설계 결과를 바 탕으로 탑재체 사출 메커니즘이 통합된 실제 발사체를 제작하며, 이론적 예측과 실제 비 행 결과를 비교·분석하여 공학적 오차 원인을 규명하는 데 본 연구의 핵심 목적이 있다.

### 1.2 연구 및 분석 방법

임무 성공률을 극대화하기 위해 수치해석 기반의 시뮬레이션을 활용한다. 실제 제작이 완료된 물로켓의 제원 및 측정된 물리량을 시뮬레이션 모델에 대입하여 최적의 발사 각 도, 내부 압력, 그리고 추진제(물)의 주입량을 산출한다. 이후 도출된 최적 파라미터를 실 제 발사 실험에 적용하고, 이론적인 시뮬레이션 궤적과 실제 비행 결과 간의 차이를 정 량적으로 비교하여 비행 중 발생하는 오차의 원인을 다각도로 분석한다.

### 1.3 설계 제한 및 특이사항

본 최종 설계에서는 유동 안정화를 위한 정류 노즐을 장착하지 않는 것으로 결정하였다. 이는 정류 노즐의 높은 제작 난이도로 인해 발생하는 조립 오차의 위험성과, 장착 시 오 히려 추진제의 배출 흐름을 방해하여 추력 손실을 유발할 수 있는 Trade-off 관계를 종 합적으로 고려한 결과이다.

## 2. 시스템 최종 설계 및 제작

### 2.1 로켓 제작 하드웨어 및 물성치

이번 장에서는 최종적으로 제작된 물로켓에 사용된 부품별 목록이다. 여기서는 각 부품 별 질량과 사용된 개수를 목록으로 나타내었다.

부품명 | 사진 | 질량, 개수 | 부품명 | 사진 | 질량, 개수
탱크 모듈 | | 80 g, 1개 | 사출장치 모듈 | | 79 g, 1개
1.5L 칠성사이다 페트병 | | 44 g, 1개 | 사출장치 상단부 | | 18 g, 1개
Fin (꼬리날개) | | 12 g, 3개 | 사출장치 하단부 + 서보 모터 | | 23 g, 1개
| | | 사출용 회전장치 + 베어링 | | 18 g, 1개
| | | 탁구공 | | 3 g, 1개

부품명 | 사진 | 질량, 개수 | 부품명 | 사진 | 질량, 개수
전자장치 모듈 | | 73g, 1개 | 노즈콘 | | 3g, 1개
Arduino Nano Ble+ 기타 전선 | | 10g, 1개
A3 Battery & socket | | 63g, 1개

### 2.2 공학적 로켓 구조 설계

앞서 언급된 두 가지의 조건을 달성하기 위해, 물로켓의 구조 설계에 있어 로켓의 비행 안정성과 사출 시스템(사출 장치와 이를 동작시키는 센서 및 연결잭)의 구조적 안정성을 핵심 고려사항으로 설계를 진행하였다. 이러한 안정성이 충분히 확보되지 않는다면, 앞서 개념설계에서 예측한 비행거리 및 정확한 사출 조건 달성에 가까워지기 어렵기 때문이 다. 다만 안정성을 확보하는 방향의 설계 변경(노즈부 질량 증가, 핀 면적 확대 등)은 정 점고도·비행거리·페이로드 탑재 여유와 같은 다른 성능 지표와 상충하는 트레이드오프 관 계에 있어, 안정성만을 일방적으로 극대화하는 방향으로 설계를 진행하기는 어려웠다. 이 에 따라 무게 배치 및 payload 배치도, 핀·노즈 형상 등 다수의 설계 변수를 반복적으로 조정하며, 안정성과 비행성능 사이의 합리적인 절충점을 만족하는 로켓 구조를 종합적으 로 고려하여 최종 설계를 결정하였다.

먼저, 최종적인 로켓의 배치도는 아래와 같이 개략도로 나타내었다.


그림 1. 로켓 구성 개략도

위 구성도에 나누어진 부분별로 하나씩 선정 이유 및 제작 과정을 설명하려고 한다.

먼저 로켓의 하단부인 탱크부 페트병과 핀 부분은 각각 뚜껑을 제거한 칠성사이다 1.5L 페트병과 물로켓 탄두 세트 내 구성품인 핀(날개)을 그대로 사용하였다. 그 이유는 아래 와 같다.

① 탱크부 페트병


그림 2. 칠성 사이다 1.5 L 페트병 높이(305 mm), 최대 반경(45 mm)

: 초기 설계 과정 시, 탱크부 페트병의 노즐 설계 또는 길이 조정을 생각하여 가공 및 절 단을 고려하였지만 이는 다음 아래의 구조역학적 이유로 그대로 사용하였다.

압력용기 설계 및 구조해석을 진행할 때 크게 두 가지를 고려하여 설계된다.

바로 탱크의 축방향에 대한 Longitudinal stress와 원주방향의 Hoop stress이다. 이러한 두 응력은 아래 그림과 같이 두께 및 탱크 길이에 따른 면적과 탱크 내부 정사영 면적에 대해 작용하는 두 힘의 평형을 통해 정의할 수 있다.


Hoop Stress를 구하는 과정은 다음과 같다.

∑Fy = 0 , 2[σ1(tdy)] − p(2rdy) = 0

σ1 =

pr
t

Longitudinal Stress를 구하는 과정은 다음과 같다.
∑Fx = 0 , σ2(2πrt) − p(πr
2
) = 0

σ1 =

pr
2t

여기서, 큰 값을 가지는 응력은 Hoop stress가 Longitudinal stress보다 2배 더 크게 작용 함을 알 수 있다. 측정한 칠성사이다 1.5L 페트병 사이다의 두께 t = 0.4mm와 반경이 가 장 큰 페트병의 가장 평평한 구간의 반경은 약 r = 45mm이다. 앞서, 시뮬레이션을 통해 정해진 압력 50psi = 0.345MPa = 0.345N/mm²에 대해 가해지는 응력은 아래와 같다.

σ1 =

pr
t

=

(0.345)(45)
0.4

= 38.81MPa , σ2 =

pr
2t

=

σ1
2

= 19.41MPa

보통 페트병을 그림 2와 같이 절단하여 사용하지 않으므로 관심 응력은 Longitudinal stress이다. 실제 PET 재질에 대한 1.5L 페트병의 인장강도를 확인할 수 없지만, 미국 특 허 US 7,303,087 B2에 따르면, PET 재질 탄산음료 병 몸통부(body region)의 배향 처리된 PET는 5% 변형률 기준 항복강도 약 89.7 MPa를 가지며, 원주방향 연신비가 축방향 대비 약 35% 높으므로 원주방향 및 축방향 버팀 응력은 순서대로 약 89.7 MPa, 66 MPa까지 버틸 수 있다고 알려져 있다. 이는 앞서 구한 σ₁ = 38.81 MPa, σ₂ = 19.41 MPa를 모두 상회하므로, 원형 그대로의 페트병은 50 psi 가압 조건을 충분히 견딜 수 있다.

그림 2. Hoop stress 작용면적 | 그림 3. Longitudinal stress 작용면적

그러나 절단한 부분에 대해 테이프나 본드로 재결합 시, 이전의 PET 강도를 잃게 되고, 테이프의 전단 접착강도는 3M 제조사 기준 최대 0.154N/mm²
, 순간접착제의 PET 표면
접합강도는 특수 가공 시 최대 4.2MPa만 버틸 수 있다. Swift supplies사의 PET에 사용하 는 순간접착제는 접착력이 매우 낮을 수 밖에 없다고 언급하기도 한다. 따라서, 이는 절 단면에서 요구되는 Longitudinal stress 19.41 MPa에도 크게 못 미치므로, 재결합된 접합 부는 앞서 정해진 압력 50 psi에 매우 불안정하게 된다.

결론적으로, 탱크부의 페트병을 그대로 사용하되, 추후 최종 설계 후 무게 중심을 조정 하는 경우 사출부 페트병의 길이와 사출 장치, 노즈콘 등의 무게를 조정하여 공력중심 대비 적절한 무게중심을 선정하였다. 이에 대한 과정은 뒤에 서술된다.

② 핀(꼬리날개)


그림 3. 핀(꼬리날개) 길이 제원

: 핀(Fin)의 역할은 비행기의 주익에 의한 양력 발생의 역할을 하는 것이 아닌 수평 및 수직 꼬리날개와 비슷한 비행안정성에 기여하는 역할을 하게 된다. 즉, 핀의 중요 역할은 공력 압력중심(CP)을 무게중심(CG) 뒤쪽에 위치시켜 로켓이 발사 후에 포물선 궤적을 자 연스럽게 그리며 날아가도록 하는 것이다. 이는 3)에서 언급될 노즈콘 또한 그 역할을 중요하게 담당한다. 이는 위의 ① 탱크부 페트병의 최대 직경 면적의 최하단에 배치하였 으며, 그 이유로는 핀(꼬리날개)이 하단에 위치할수록 압력중심(CP) 또한 노즈콘 끝점으 로부터 멀어지는 방향으로 배치되기 때문이다.

③ 노즈콘

: 노즈콘(Nose cone) 사용 방식 또한 핀(꼬리날개)와 똑같이 탄두 세트 내 상용품으로 사 용하려 했으나, 초기 개념설계 과정 시 비행거리 50 m에 근접하여 도달하기 위해 설정 한 최대 질량 한계를 물로켓 제작 도중 넘는 문제로 50 g 정도의 무거운 노즈콘을 대체 해야 했다. 따라서, 설계 과정 중 충분히 무게 중심이 압력중심 대비 앞쪽에 위치한 상태 를 유지한 채로 가볍고 매끄러운 폴리프로필렌(Polypropylene), PP 재질의 노즈콘으로 대 체하였다. 이는, 흔히 문서를 보관하여 사용하는 클리어 파일을 이용하여 제작하였다. 고 무 노즈콘 대비 충격에 대한 안정성은 떨어지지만, 미션 수행을 더욱 최우선으로 삼아야 하므로 다음 재질을 택했다.

노즈콘 형상에 있어, MIT 로켓팀에 따르면 아음속 비행 상태에서는 형상이 로켓의 항력 에 큰 영향을 미치지 않는다고 언급한다. 단순 원뿔 형상 대비 자주 사용되는 ogiv 또는 von Karman 형상의 항력 감소는 발생하나 이는 작은 수치라고 언급한다. 앞서 시뮬레이 션 상에서 얻은 로켓의 최대 속도 25 m/s를 마하수로 환산하면(해수면 물성치 기준) M=0.074가 된다. 이는 비압축성 아음속 구간에 걸치게 되므로 크게 형상을 고려할 필요 가 없다고 판단하였다. 따라서, 제작에 가장 용이한 원뿔형 노즈콘을 택하게 되었다. 노 즈콘의 최대 직경은 페트병의 직경에 맞게 90 mm로 설정하였으며, 압력 중심(CP) 결정 에 영향을 주는 노즈콘의 높이는 Open rocket을 통해 조절하며 구한 결과,

(최대직경) ∶ (노즈콘 높이) = 1 ∶ 2

의 비율이 가장 적합하다고 판단하여 1:2의 비율로 결정하여 제작하였다. 따라서, 노즈콘 높이는 180mm로 설정하였다.

이제 압력중심의 큰 역할을 맡는 노즈콘과 핀(꼬리날개)이 언급되었으므로 최종 설계된 로켓을 기준으로 비행안정성을 검토한 과정을 설명한다. 보통 추력제어(TVC, Thrust Vector Control)를 이용하지 않는 자유비행 로켓의 경우, 노즈콘의 끝점을 원점 기준으로 두면 원점과 무게 중심(CG) 사이의 거리가 원점과 압력 중심(CP) 사이의 거리보다 짧아 야 한다. 즉, 같은 선상에 놓인 CG와 CP 중 CG가 앞서 위치해야 한다. 이러한 기준은 반드시 만족되어야 할 필수조건이다. 그 이유는 아래와 같다. 로켓이 비행 중 바람이나 미세한 교란에 의해 받음각(angle of attack)이 발생했을 때, 공력에 의한 측면 방향의 힘 이 압력중심(CP)이라는 한 점에 작용한다고 등가적으로 처리할 수 있기 때문이다. 이 힘 이 무게중심(CG)을 기준으로 만들어내는 모멘트의 방향이 로켓의 안정성 여부를 결정짓 는데, CP가 CG보다 후방(꼬리 방향)에 위치할 경우 받음각으로 인한 공력모멘트가 기수 를 다시 비행방향(상대풍 방향)으로 되돌리는 방향, 즉 받음각을 감소시키는 복원모멘트 (restoring moment)로 작용한다. 이는 화살의 깃털이나 풍향계의 꼬리날개가 큰 표면적 으로 바람을 받아 진행방향을 따라 정렬되는 원리와 동일하다. 반대로 CP가 CG보다 전 방에 위치하면 공력모멘트는 받음각을 오히려 증가시키는 발산모멘트(diverging moment)로 작용하여, 받음각이 시간에 따라 계속 커지다가 결국 텀블링으로 이어진다.

핀(꼬리날개)을 로켓 후미에 배치하는 이유도 후방 표면적을 증가시켜 CP를 CG보다 뒤 로 이동시킴으로써 이러한 복원모멘트를 확보하기 위함이다.

먼저, 설계 및 제작이 완료된 로켓의 무게중심 CG를 찾는 방법은 두 가지 방법이 있다. 첫째로는 실물의 로켓에 실을 고정하여 수평이 되도록 하는 지점을 찾는 방법과 두번째 로는 실물의 길이, 형태 등을 반영한 CAD 프로그램 상에서 찾는 방법이다. 만약, 실물의 로켓 제작 후 무게중심이 과도하게 앞 또는 뒤에 위치하면 수정하기 시간과 비용이 들게 되므로, 개념 설계 및 형상 설계를 마치고 CATIA V5 프로그램을 이용하여 무게중심을 측 정하였다. 그 과정은 아래와 같다.

1) 사용된 부품별 Assembly를 진행한다.

: 먼저, 사용된 센서부터 시작하여 페트병, 핀, 사출 장치 등 형상을 적절히 배치한다. 여 기서 상용품인 Arduino Nano ble, SG90 서보모터는 GrabCad 사이트에서 공유하는 stp 형상 파일을 다운받아 사용하였고, 그 이외에 없는 부품들은 직접 수치를 측정하여 형상 화했다.


그림 4. Assembly된 상태의 물로켓 형상

2) 앞서 측정한 각 부품별 질량을 Catia 상에 Apply Material로 반영한다.

: 각 부품별 목록에서 표시한 측정된 질량을 반영해야 한다. Catia v5 상에서 이를 진행하 는 이유는 형상에 따른 부피를 자동적으로 계산하여 제공하기 때문에 측정된 질량과 계 산된 부피를 가지고 밀도로 반영해 어느 정도 정밀한 무게중심을 구할 수 있기 때문이

다. 모든 과정은 아래의 예시를 반복적으로 적용한 것이다.

가. 사출장치 윗부분 part를 활성화한다.

나. 활성화된 part에 실행 - c:apply materia을 입력하여 재질에 맞게 설정한다.


다. 자동 계산된 부피와 질량으로 밀도를 계산한다.


ρ = (18 × 0.001) / (1.659 × 10⁻⁵

) = 1084.99 kg/m³


라. 계산된 밀도를 설정한 재질의 Properties–Analysis에 재반영한다.

이렇게 추가된 모든 부품들에 대해 밀도를 반영하고, Measure Inertia 기능을 사용하면 무게중심은 아래와 같이 뜨게 된다.

그림 5. 물로켓 Assembly Product에 대한 무게중심 좌표 및 특성

무게중심점을 생성하여 노즈콘으로부터의 거리를 측정하면 아래와 같다.


그림 6. 노즈콘 끝점으로부터 무게중심 CG 사이의 거리: 256.943 mm

이제 CP를 구하는 과정을 거쳐야 하는데, 이는 Catia v5 상에서 지원하지 않는다. 따로 이를 구함과 동시에 시뮬레이션으로 정한 최적 조건인 발사각 50도 및 물 0.58L을 반영 해 로켓의 운동특성을 분석하고자 OpenRocket 프로그램을 사용하였다. 여기서도 처음 진행하는 과정은 Catia v5와 동일하게 Nose cone 및 Body, Fin에 대한 형상 수치를 반영 하고 CG는 Catia 상의 무게중심이 더욱 정확하기에 이를 아래 그림과 같이 Override 기 능을 통해 앞서 측정한 총 질량과 무게중심 위치를 강제적으로 부여하였다.


그림 7. 물로켓의 총 질량 및 CG 강제 부여 과정

개략적인 로켓 외형을 나타내고, 노즈콘과 핀(꼬리날개)의 수치를 반영하여 정적 상태에 서의 CP를 구한 결과 아래와 같다.


그림 8. Catia v5의 CG와 Open Rocket의 CP 분포

위에 구해진 위치는 로켓의 건조 질량에 대한 CG 및 CP 분포이며, 정적 상태에 대한 일 시적인 위치이다. 이는 보통 1.000캘리버의 안정성 기준에는 미달이지만 안정성을 갖춤 에는 변함이 없다. 초기 로켓의 상태는 물 0.58 L가 탑재된 상태로 발사될 것이다. 따라 서, 이를 반영한 무게 중심을 보면 아래와 같다.


그림 9. 물 0.58 L를 반영한 로켓의 변화된 CG

변화한 CG는 앞서 건조질량 대비 11.4 cm 더 뒤로 이동한 것을 확인할 수 있다. 이는 CP보다 뒤에 위치하게 되므로 정적 마진만으로는 −0.997캘리버의 심각한 불안정 상태로 나타난다. 다만 이 값은 로켓이 정지해 있거나 막 발사된 직후, 즉 동압이 거의 0에 가까 운 순간이다. 시작 직전 속도가 거의 0일 때이기 때문이다. 실제 공력모멘트는 동압에 비 례하므로 이 시점에는 모멘트가 거의 작용하지 않는다. 이후 로켓이 가속하며 동압이 증 가하지만, 물이 0.1~0.2 s라는 매우 짧은 시간 내에 완전히 분사되며 CG가 동시에 빠르 게 전방으로 이동하기 때문에 이 불안정성을 크게 고려할 필요가 없다.

또 하나 고려할 점으로는 로켓이 비행 궤적 중 취하는 자세와 풍향 간의 관계 등등에 따 라 CP도 변화할 수 있다. 따라서, 이를 확인하고자 Open rocket에서 제공하는 Simulation을 진행하였다. 앞서 반영한 물 0.58 L는 개념설계 진행 시 가정하였던 final.m 파일의 물성치를 반영해 Motor 형식으로 반영한 것이다. 아래는 실제 발사 장소에 대한 위도, 경도, 고도를 반영하고, 실제 당시 풍향 및 풍속, 기온, 발사각을 반영하여 설정한 값이다. 당시 풍속 3 m/s에서 학교 운동장 주변의 건물들로 인하여 체감상 바람이 거의 불지 않은 것으로 느꼈다. 그래서 설정에 Tuburlence intensity를 10%로 적게 반영하였 고, 발사각의 경우 지면 기준 수직선에 대하여 각도를 반영하므로 50도 발사의 경우, 40 도를 입력해주어야 한다.


그림 10. 물로켓의 발사 환경 설정

다음과 같이 설정하고 Plot data 설정에서 시간 t(x축)에 따른 여러 파라미터 값들의 그래 프를 확인할 수 있다.


그림 11. 시간-고도, 전체 속도, 수직 성분 속도에 대한 그래프

먼저, 그래프를 보면 저 0.12s 지점에서의 급격한 속도 변화를 볼 수 있다. 이는 물 + 압 축된 공기가 완전히 분사되기까지 0.12s라는 매우 짧은 시간이 걸림을 앞서 예상한 것과 같다는 것을 알 수 있다. 이때, CP, CG의 변화도 함께 살펴본다.


그림 12. 시간-CP, CG, Stability Margin Caliber에 대한 그래프

안정마진은 비행 전 구간에 걸쳐 약 0.243~0.276캘리버의 매우 좁은 범위 내에서 유지 되었으며, 단 한 차례도 음의 값으로 전환되지 않았다. 또한, 0을 노즈콘의 끝점으로 기 준으로 삼아 보았을 때, 물의 분사가 끝마치고 나서 비행 중에 CG는 257mm, CP는 279~282mm 사이에 위치하는 안정적인 특성을 보여준다. 이는 곧 최종 실제 비행 결과 에서 안정적으로 발사된 결과를 낳은 핵심 요인이라고 생각한다.

④ 사출부 페트병(사출장치)

: 먼저, 사출부 페트병 내부에는 회전형 실린더를 통한 탁구공 자동 사출 장치가 포함되 어 있다. 사출장치가 들어있는 페트병의 형태는 아래 사진과 같다.

먼저, 최대 직경의 굴곡이 없는 부분만 잘라 사용하였다. 그러한 이유는 앞서 개념설계에 서 언급한 능동적 SlingShot 구조의 발사장치를 구현하려면 탁구공이 발사되기 전 탁구 공이 접촉되어 있어야 하는 면이 일정하게 곡률을 가져야 한다. 그렇지 않고 굴곡이 지 거나 울퉁불퉁한 사이다 페트병 면에 접촉하게 되면 실린더 회전 시 탁구공이 걸려 발사 될 수 없기 때문이다. 탁구공의 정식 길이 40mm를 기준으로 실린더 및 사출부의 면적 에 offset을 반영하여 재단 및 설계하였다. 여기서 특이한 점은 실린더 옆 개폐문을 고정 시켜 아래의 SG90에 의해 회전 시 열고 닫는 문 역할을 하도록 제작하였다. 이러한 부 분을 고려한 이유는 열린 면적에 있어 유동박리에 의한 큰 항력이 발생될 수 있기 때문 이다.


그림 13. 시간-페트병 사출부 면적, 실린더 및 개폐문 면적

그림 14에서 보이다시피 위 사출장치를 분해하여 나타낸 형태이다. 여기서 위에 보이는 상판과 하부 판, 그리고 회전형 실린더는 PLA+ 소재의 필라멘트를 이용하여 3D Printer 로 제작하였다. 이는 직접 설계를 진행하며 반복적인 예행연습과 수정 과정을 통해 얻은 결과물이다. 맨 아래 사용된 SG90을 아래의 Board에 고정되어 있고, 그 SG90 서보 모터 에 회전형 실린더의 회전축과 고정되어 있다. 그리고 상단의 회전축에 베어링을 장착하 고, 그 베어링을 상부 Board의 베어링 고정 홈에 끼워 서보 모터 출력에 따라 부드럽게

그림 14. 사출장치 구성도

회전되도록 만들었다. 그리고 그 위에는 배터리 및 소켓을 끼워 넣을 수 있는 공간과 함 께 위에 Arduino Nano Ble 센서를 스펀지로 고정시켜 넣을 수 있도록 구성했다.

이제 앞서 개념설계에서 진행한 사출 시간을 재계산하여 이를 예측한 비행거리에서의 도 달 시간에서 차감하여 아두이노의 정확한 사출 신호를 보내도록 해야 한다.

앞서 개념설계에서 언급했던 고무줄 및 패드 간의 관계식을 바탕으로 수치해석적인 계산 과정을 통해 얻은 탁구공 사출 시간 trubber, 회전형 실린더가 장착된 상태에서의 서보 모터 작동 시간 tservo, 그리고 센서 간 통신 주파수에 따른 항전장비 작동 시간 telec (개 념 설명을 복습하면 내용이 과다할 것이라 예상하여 생략함.) 세 가지 시간을 모두 더해 예측했던 시간이 ttotal = 160.7ms 이었다.

이전에는 제작하지 않은 상태에서 예측을 위해 계산을 진행하였지만, 이번 최종 설계 과 정에서는 실제로 만든 로켓을 구동한 영상을 찍어 프레임 분석을 통해 특정 고도 또는 Failsafe에 대한 신호가 노트북에서 띄어지는 순간부터 탁구공이 페트병에 완전히 나온 직전까지의 시간을 측정하였다. 이는 미리 시간지연을 제거한 과정으로 얻은 것이 아닌, 신호만 주는 테스트를 통해 시간지연 ttotal을 실험적으로 측정한 것이다.

먼저 공의 사출 순간을 더욱 정확히 포착하기 위해, 핸드폰에서 지원하는 슬로우 모션 카메라로 촬영하고, 이를 동영상 운동 분석 사이트를 통해 측정하였다. 먼저, 핸드폰 슬 로우 모션 촬영 시 240FPS, 운동 분석 사이트에서의 분석 과정은 30FPS로 측정하였다. 즉, 운동 분석 사이트에서의 30FPS 기준 시간 차이를 구하면 이에 대해 8배의 240FPS의 시간 특성을 반영하여 그 시간 차이에 1/8배를 해주면 된다.


그림 15. 사출장치 작동 직전과 탁구공이 사출 패드로부터 떨어지기 직전 시각

58.367 – 57.033 = 1.334s의 시간 차이가 발생되고, 여기에 1/8배를 하면

1.334/8 = 0.16675s

즉, 탁구공이 완전히 사출되기까지 167ms의 시간이 발생된다. 여기서 신호가 어느 시점 부터 전송을 시작하였는지는 파악할 수가 없기 때문에 앞서 개념설계에서 센서 스펙을 통해 구한 telec = 33.5ms를 오차범위로 두면 133.5~210.5ms 범위에서 총 작동시 간이 정해짐을 알 수 있다. 여기서 중간값 167ms가 최종 작동 시간일 경우, 앞서 예 측했던 ttotal = 160.7ms 와 단 7ms 차이만 나는 것을 알 수 있다. 그래서 최종적으로 Arduino Nano Ble에 컴파일하는 코드에 반영될 때, 25m 상공에서의 33.5ms에 의한 거리 값이 단 몇 cm의 오차를 발생시킴을 인지하고 이를 무시하는 가정으로 167ms의 시간 지연을 제외해서 설정하였다.

### 2.3 비행 제어 및 데이터 수집 시스템

6조의 물로켓은 아두이노 나노 BLE Sense 제품을 탑재하여 비행 제어를 수행한다. 해당 제품은 가속도계 및 자이로스코프가 통합된 IMU(Inertial Measurement Unit) 센서 기반의 FC(Flight Controller) 역할을 하며, 아두이노 IDE 환경에서 로켓의 자세 및 비행 거리를 실시간으로 추적한다. 수집된 비행 데이터는 BLE(Bluetooth Low Energy) 기능을 통해 지 상국(GCS)과의 무선 통신으로 송신된다.

### 2.3.1 비행 제어

비행 제어 프로세스는 센서로부터 비행 데이터를 받아와 현재 로켓의 위치와 자세를 추 정하는 항법 알고리즘 체계와, 추정된 정보를 바탕으로 서보 모터에 구동 신호를 인가하 는 제어 구동 체계로 구분된다. 시스템의 전반적인 유한 상태 기계(FSM) 구조는 다음과 같다. 아두이노의 전체적인 동작 구조는 다음과 같다.

① STATE_READY (대기): BLE 연결을 기다리며, 하드웨어 초기화 후 대기하는 상태.

② STATE_CALIBRATING (센서 보정): 300개의 IMU 샘플을 수집하여 초기 기울기 (Pitch)와 센서 오차(Bias)를 계산.

③ STATE_STANDBY_DELAY & STANDBY (발사 대기): 보정 완료 직후 무선 데이터 통신 안정화를 위해 500ms의 가드 타임을 가진 후, 발사 충격을 감시.

④ STATE_FLYING (비행 및 항법): 실시간으로 가속도와 자이로 데이터를 연산하여 이 동 거리를 계산하고 사출 조건을 감시.

⑤ STATE_EJECTED (사출 완료 및 착륙 대기): 서보 모터를 구동하여 낙하산을 사출한 뒤, 기체가 지면에 안착할 때까지 물리적 충격 변화를여기에 수식을 입력하세요. 감시.

⑥ STATE_DUMPING (데이터 전송): 비행 중 RAM 버퍼에 저장된 이진 데이터를 BLE 고속 패킷으로 지상국에 전송한 후 시스템을 리셋.

- 비행 거리 계산 알고리즘

① 초기 자세 및 센서 오차(Bias) 산출

보정 단계(STATE_CALIBRATING)에서 기체가 지면에 정지해 있을 때 수집된 300개의 데 이터 평균을 활용한다.

- 초기 피치 각도(θinit): 정지 상태에서 중력 가속도가 X, Y축 합성 성분과 Z축에 걸리는 비율을 이용하여 계산한다.

θinit = atan2 (a̅̅z̅̅,raw ̅̅̅̅, √ax,raw
2 | + ay,raw
| 2

̅̅̅̅̅̅̅̅̅̅̅̅̅̅̅̅̅̅̅̅̅̅
)
- Z축 가속도 오차(Biasz
): 중력 성분을 제외하고 센서 자체에서 발생하는 하드웨어 오프셋을 추출한다.

Biasz = (a̅̅z̅̅,raw ̅̅̅̅ − sin(θinit)) × g

② 비행 중 실시간 피치 각도 추정

비행 상태(STATE_FLYING)에 진입하면, 정적 상태를 벗어났으므로 가속도 대신 자이로스 코프(Y축 각속도)를 시간(dt)에 대해 적분하여 현재 기울기를 갱신한다.

θcurrent = θprev + (−ωy − Biasωy) × dt

③ 3차원 동적 합성 가속도 연산

센서의 원시 값(g 단위)을 물리 단위(m/s²
)로 변환하고, 자이로스코프로 추정한 기울기
기반의 중력 가속도 성분과 초기 오차를 제거하여 순수하게 로켓의 모터 힘으로 인해 발

생한 수평 방향 가속도(aℎorizontal)를 계산한다.

- X, Y축 순수 가속도: ax = ax,raw × g, ay = ay,raw × g
- Z축 순수 가속도: az = (az,raw − sin(θcurrent)) × g − Biasz
- 최종 기체 진행 방향의 합성 가속도:

aℎorizontal = √ax
2 + ay

2 + az
2

④ 가속도 이중 적분을 통한 속도 및 거리 추정

최종 가속도 성분을 시간에 대해 연속적으로 누적 적분하여 실시간 속도와 최종 이동 거 리를 도출한다.

- 속도 계산 (1차 적분): v(t) = v(t − dt) + aℎorizontal × dt
- 거리 계산 (2차 적분): s(t) = s(t − dt) + v(t) × dt
- 노이즈 가드: 가속도 값이 설정한 데드밴드(ACCEL_DEADBAND = 0.20)보다 작으

면 정지 상태로 간주하여 가속도를 0으로 처리함으로써 센서 드리프트(Drift)를 1차적으로 억제한다.

계산된 거리는 글로벌 좌표계에서의 직선 이동 거리가 아니기 때문에 과제의 조건에 맞 추기 위해서 직선상 25 m일 때의 포물선 궤적의 거리를 계산하여 27.7 m를 target distance로 설정하였다.

- 사출 트리거 조건

서보에 신호를 전달하는 기준은 미션의 실패를 방지하고자 아래와 같이 두 가지로 나누 어 진행하였다.

① 계산된 거리가 target distance(27.7 m)에 도달했을 때

② 비행 시간이 1.453 s가 되었을 때

비행 거리를 계산해서 25 m 상공에서 탁구공을 사출하는 것이 목적이지만 물로켓의 비 행 시간이 너무 짧고 아두이노의 센서 성능이 물로켓의 진동과 같은 외란에 영향을 받아 제대로 사출되지 않았을 때를 가정하여 이론상 25 m 지점까지의 비행 시간을 계산하여 코드에 반영하였다.

### 2.3.2 데이터 저장 및 덤프 메커니즘

메모리와 무선 대역폭을 효율적으로 사용하기 위해 고안된 데이터 처리 방식이다.

- 링 버퍼 로깅: 비행 상태 동안 20ms 주기(50Hz)로 최대 120개의 데이터 세트 (MAX_LOG_SAMPLES)를 RAM 배열에 실시간 저장한다.
- 착륙 판정: 사출 후 3축 가속도의 절대 크기 합성 벡터(√ax
2 + ay

2 + az
2)가 1.0G(지

구 중력) 부근에서 1000ms(1초) 동안 안정되게 유지되면 지면에 착륙한 것으로 간주한다.

- 이진 패킷 전송(Binary Dump): 착륙 후 가독성이 떨어지고 패킷 크기가 큰 문자열 (String) 대신, 구조체 구조를 1바이트 크기의 배열로 직렬화하여 BLE 패킷 규격에 맞춰 고속 전송(bleWriteBinary)한다. 부동 소수점(float) 데이터는 용량을 줄이기 위해 10 또는 100을 곱해 int16_t형 정수로 압축 전송하는 방식을 취하고 있다.

해당 데이터 로그는 html로 만든 BLE 통신 창을 통해서 받을 수 있다. Html의 구성은 아 래와 같다.


아두이노 연결 및 제어를 위한 각종 명령을 보낼 수 있는 버튼을 상단에 구성하였고 하 단에는 로켓의 현재 상태와 비행 로그를 받을 수 있도록 창을 배치하였다.

현재 창에 있는 로그는 아두이노로부터 임의의 비행 로그를 받은 모습이다.

## 3. 시뮬레이션 예측 vs 실제 비행 시험 결과

### 3.1 데이터 수집 시스템 운영 결과 및 한계

발사체의 총 질량을 최소화하기 위해 SD 카드 등 내부 저장 장치를 배제하고, 블루투스 통신을 활용하여 실시간 궤도 데이터를 수신하도록 시스템을 설계하였다. 지상 테스트 결과, 사출 장치 및 초기 시스템 구동은 정상적으로 작동하였으며 사양에 기반한 통신 거리 역시 목표치(50~100 m)를 충족하였다.

그러나 실제 발사 운용 과정에서 블루투스 통신 장애가 발생하여 유효 통신 거리가 예상 보다 크게 제한되었다. 이로 인해 비행 중 실시간 궤도 데이터를 안정적으로 수신하는 데 한계가 발생하였다. 이를 보완하기 위해 통신 데이터 대신 비행 영상을 기반으로 한 궤적 추적 기법을 도입하여, 실제 비행과 가장 유사한 모델을 재구성하는 방식으로 궤도 데이터를 추정하고 원인 분석을 진행하였다.

### 3.2 영상 분석 기반 비행 궤적 및 사출 데이터 복원

블루투스 통신 장애로 인한 데이터 수신 한계를 극복하기 위해, 비행 촬영 영상을 정밀 분석하여 실제 비행 궤적과 사출 데이터를 다음과 같은 방법으로 복원하였다.

- 영상 기반 2차원 궤적 복원: 고정된 배경을 기준으로 비행 영상을 프레임 단위로 추 적하여 로켓의 위치 좌표를 추출하였으며, 이를 바탕으로 전체적인 2차원 비행 궤적 형상을 복원하였다.
- 사출 장치 작동 시점 정밀 측정: 촬영된 영상을 0.01초 단위의 프레임으로 정밀하게 분할하여 탁구공이 사출되는 정확한 시각을 포착하고, 이를 실제 비행 데이터 분석 에 반영하였다.
- 비례식을 활용한 사출 위치 역산: 영상으로부터 도출된 2차원 궤적 상의 화면 비율 과 실제 지상에서 측정한 총 비행 거리를 연동하여, 실제 사출이 발생한 정확한 공 간적 위치를 역산하여 추정하였다.
- 유효 비행 거리 기반 궤도 예측: 실제 로켓의 최종 착탄 지점이 발사대와 50m 목표 지점을 잇는 기준 축과 완벽한 일직선을 이루지는 않았으나, 비교적 안정적으로 비 행했기 때문에 좌측으로의 편차가 크지 않다고 판단하여 측정된 도달 거리를 전체 궤도 거리를 예측하고 해석하는 데 유효한 데이터로 활용하였다.

### 3.3 시뮬레이션 파라미터 보정 및 최적 발사 조건 재산출

실제 비행 환경과 제작된 발사체의 물리적 특성을 보다 정확하게 반영하기 위해 시뮬레 이션 파라미터를 다음과 같이 보정하였다.

- 유량 계수 상향 조정: 시스템의 실제 유동 효율을 반영하여 물의 유량 계수를 0.85 에서 0.9로, 공기의 유량 계수를 0.9에서 0.95로 상향 조정하였다.
- 항력 계수 하향 조정: 발사체가 뾰족한 원기둥 형태를 띠고 있으며, 사출구를 여닫이 식으로 설계하여 공기역학적 마찰 저항이 감소한 점을 반영해 공기 저항 계수를 0.25로 하향 조정하였다.
- 건조 질량 실측 값 반영: 초기 설계 단계에서 예측된 건조 질량은 0.1467 kg이었으 나, 실제 제작 완료 후 측정한 결과 0.2357 kg으로 확인되어 이를 시뮬레이션 변수 에 적용하였다

### 3.4 시뮬레이션 VS 실제 비행 데이터 비교

시뮬레이션 결과


실제 비행 궤적

사출 시각 및 위치 추정


초기 발사각도 | 50°
채워진 물의 양 | 0.58 L
탁구공 분리 시점 및 거리 | 약 2.05 s / 23.7 m부근
최대 비행거리 | 56.6 m
목표(50 m)와의 오차 | +6.6 m
총 체공시간 | 3.8 s

### 3.5 결과 분석

비교항목 | 시뮬레이션 결과 | 실제 비행 결과 | 차이
초기 발사각 / 채워진 물의 양 | 50° / 0.58 L | 50° / 0.58 L | -
최대 비행거리 | 49.04 m | 56.6 m | +7.56 m
목표(50 m)와의 오차 | -0.96 m | 6.6 m | -
총 체공 시간 | 3.16 s | 3.8 s | +0.64 s
탁구공 분리 시점 | 1.548 s | 2.05 s | +0.502 s
탁구공 분리 위치(거리) | 25 m | 약 23.7 m | -1.3 m (도달 전 사출)
- 비행 거리 및 체공 시간의 증가: 실제 로켓의 최대 비행 거리는 56.6 m로 예측치 대 비 약 7.56 m를 초과 비행하였으며, 총 체공 시간 역시 3.8초로 시뮬레이션보다 길 게 측정되었다.
- 사출 시스템의 작동 지연: 시뮬레이션 상에서는 1.548 s에 정확히 25 m 지점을 통과 하며 탁구공이 사출될 것으로 예측되었다. 그러나 실제 영상 분석 결과, 사출은 약 2.05 s 시점에 이루어졌으며, 이때의 거리는 목표치인 25 m에 미치지 못하는 23.7 m 부근으로 확인되었다.

## 4. 오차 원인 분석

### 4.1 배풍 효과를 고려한 오차 발생


당시 그 지역의 풍향 및 풍속은 서풍 3 m/s로 관측되었다. 실제 발사에서 공기저항 및 측, 후풍의 영향을 받았을 가능성이 있다. 배풍이 부는 환경에서 발사체가 경험하는 공기 역학적 항력은 대지 속도가 아닌 유동에 대한 상대 속도를 기준으로 산출된다. 이를 기 반으로 수평방향의 운동방정식을 작성하면 다음과 같다.

m

dvx
dt = −

1
2

ρair(vx − vwind)

2CDArocket

배풍이 존재하는 경우 상대속도가 감소하여 발사체가 받는 동압이 낮아진다. 이는 항력 의 감소로 이어져 로켓의 수평 방향 속도 감쇠를 완화시키며, 결과적으로 체공 시간 동 안의 총 비행 거리를 증가시키는 주된 원인이 될 수 있다.

### 4.2 유량계수를 과소평가한 오류 발생


초기 시뮬레이션 모델에서는 마찰 및 유맥 수축 현상에 의한 에너지 손실을 고려하여 물 과 공기의 유량계수를 각각 보수적인 값(0.85~0.95)으로 설정하였다. 본 절에서는 해당 유량계수의 과소평가가 궤적 산출에 미친 영향을 분석하기 위해, 마찰 손실이 전혀 없는 이상적인 노즐 조건인 유량계수 1을 가정하여 시뮬레이션을 재 수행하였다. 유량계수를 1.0으로 상향 조정한 결과, 시뮬레이션 최대 비행거리가 실제 비행 시험 결과(56.6 m)와 오차율 0.5% 이내로 매우 유사해지는 경향을 확인하였다. 이는 초기 모델링 단계에서 유 량계수가 과소평가되었음을 시사한다. 다만 점성 유체인 물이 노즐을 통과할 때 마찰 저 항이 0이 되는 것은 유체역학적으로 불가능하다. 따라서 도달 거리의 일치는 순수하게 유량계수가 1.0이기 때문이라기보다는, 다른 추가적인 요인들이 복합적으로 작용한 결과 임을 알 수 있다.

### 4.3 사출 시스템의 오차 발생

사출 시스템의 설계 값은 궤적 이동 거리는 28.26 m이고, fail safe 값은 1.548 s이 작동 조건이었다. 그러나 발사 후 1.548 s가 아닌 2.05 s에 사출되는 것이 관찰되었다. 아두이 노 MCU의 센서 데이터 처리 시간 및 서보 모터가 물리적으로 동작하여 개폐문이 열리 는 데까지 걸리는 기계·전자적 지연 시간이 시뮬레이션에 완벽히 반영되지 못했고, 발사 시각을 인지하는 알고리즘에서 지연이 발생했을 가능성도 배제할 수 없다.

### 4.4 아두이노 동작으로 인한 오차

아두이노는 사출 트리거를 두 가지로 사용하는데 그중 비행 시간이 1.453 s 가 되면 무 조건 발사하는 조건이 있어서 탁구공 사출 시간은 비행 시작 이후 1.453 s를 넘을 수 없 다. 하지만 동영상으로 분석한 결과 탁구공의 사출 시간은 2.05 s이다. 이는 아두이노가 발사시간을 완벽하게 측정하지 못했다는 의미이고 이는 아두이노의 로켓 발사 감지 메커 니즘과 관련이 있다.

로켓의 발사 감지 메커니즘은 로켓의 축 방향 가속도가 1.4 G를 기준으로 그 이상이 되 면 발사가 되었다고 감지하고 시간을 측정한다. 이 메커니즘은 발사와 동시에 시간을 측 정하는 것이 아니기 때문에 발사, 감지, 측정이라는 과정 동안 시간 지연이 발생한 것으 로 생각할 수 있다.

## 5. 출처

1) PET재질 1.5L 탄산음료 페트병 항복강도

: https://www.sciencedirect.com/science/article/abs/pii/S0014305705002272
2) 3M 테이프 데이터시트

: multimedia.pdf
3) PET 플라스틱용 순간접착제의 성능

: Choosing a Super Glue for Different Types of Plastic (https://www.swiftsupplies.com.au/blog/news-and-blog/our-best-super-glues-for-plastic-part-2-choosing-super-glue-different-types-plastic/)
4) MIT Rocket Team, How to : Choose a Nose cone
: How to: Choose a Nose Cone - MIT Rocket Team - MIT Wiki Service (https://wikis.mit.edu/confluence/display/RocketTeam/How+to:+Choose+a+Nose+Cone)
5) 자바실험실 – 동영상 운동 분석 (화면 포인팅)
: 동영상 운동 분석 (화면 포인팅) - 자바실험실 (https://javalab.org/ko/motion_shot/)

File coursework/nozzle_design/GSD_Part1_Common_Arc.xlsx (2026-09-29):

6.123233996e-15 | 100 | 0
0.7933231565 | 100.0031469 | 0
1.586596383 | 100.0125872 | 0
2.379769755 | 100.0283205 | 0
3.17279335 | 100.0503458 | 0
3.965617258 | 100.0786615 | 0
4.758191582 | 100.1132661 | 0
5.550466439 | 100.1541572 | 0
6.342391966 | 100.2013324 | 0
7.13391832 | 100.2547885 | 0
7.924995686 | 100.3145224 | 0
8.715574275 | 100.3805302 | 0
9.50560433 | 100.4528077 | 0
10.29503613 | 100.5313505 | 0
11.08381999 | 100.6161536 | 0
11.87190627 | 100.7072115 | 0
12.65924536 | 100.8045187 | 0
13.44578771 | 100.908069 | 0
14.23148383 | 101.0178558 | 0
15.01628425 | 101.1338723 | 0
15.8001396 | 101.2561111 | 0
16.58300053 | 101.3845646 | 0
17.36481777 | 101.5192247 | 0
18.14554212 | 101.6600829 | 0
18.92512444 | 101.8071303 | 0
19.70351566 | 101.9603577 | 0
20.48066681 | 102.1197554 | 0
21.25652896 | 102.2853134 | 0
22.03105328 | 102.4570213 | 0
22.80419103 | 102.6348683 | 0
23.57589355 | 102.8188432 | 0
24.34611227 | 103.0089343 | 0
25.11479872 | 103.2051299 | 0
25.88190451 | 103.4074174 | 0
26.64738137 | 103.6157841 | 0
27.41118112 | 103.8302171 | 0
28.17325568 | 104.0507026 | 0
28.93355711 | 104.277227 | 0
29.69203753 | 104.5097759 | 0
30.44864923 | 104.7483346 | 0
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

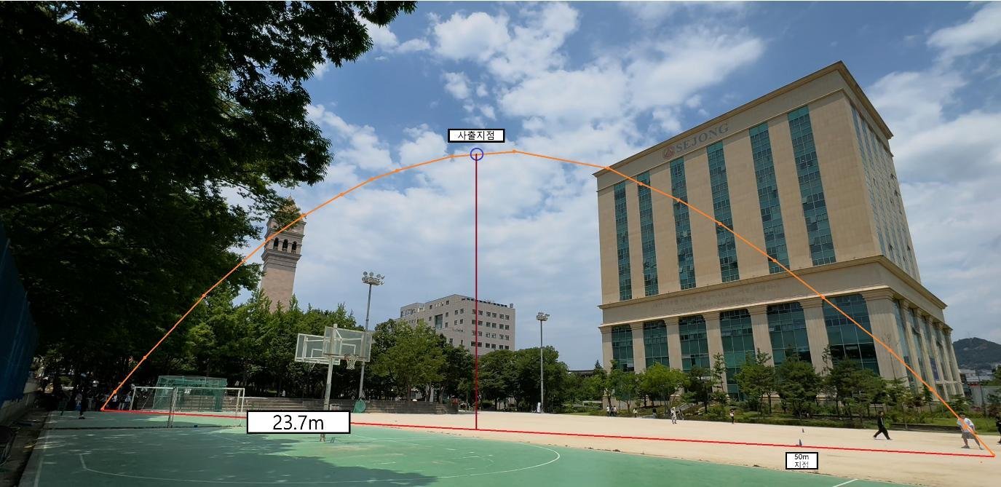
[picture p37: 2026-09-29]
docs/images/flight_ejection_point.jpg

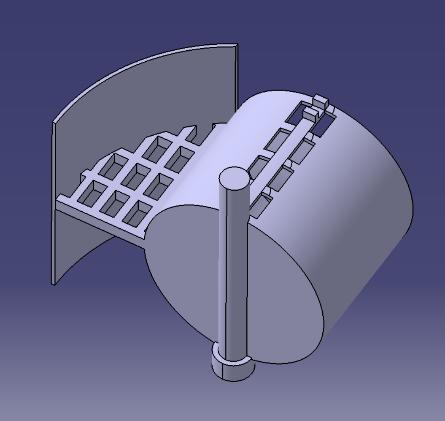
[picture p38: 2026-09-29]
docs/images/ejection_cylinder.png

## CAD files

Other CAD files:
cad/design_v1_link_door/Door_left.CATPart
cad/design_v1_link_door/Door_right.CATPart
cad/design_v1_link_door/Integer.CATPart
cad/design_v1_link_door/Part1.CATPart
cad/design_v1_link_door/Part14.CATPart
cad/design_v1_link_door/Spring.CATPart
cad/design_v1_link_door/cover.CATPart
cad/design_v1_link_door/dmu_base.CATPart
cad/design_v1_link_door/door_hinge.CATPart
cad/design_v1_link_door/door_link.CATPart
cad/design_v1_link_door/early_sketch/Part1.CATPart
cad/design_v1_link_door/early_sketch/Part2.CATPart
cad/design_v1_link_door/early_sketch/Part3.CATPart
cad/design_v1_link_door/early_sketch/Part4.CATPart
cad/design_v1_link_door/early_sketch/Product1.CATProduct
cad/design_v1_link_door/ejection2.CATProduct
cad/design_v1_link_door/ejection_assembly.CATProduct
cad/design_v1_link_door/link_dmu.CATProduct
cad/design_v1_link_door/parellel_link.CATPart
cad/design_v1_link_door/pingpong ball.CATPart
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
